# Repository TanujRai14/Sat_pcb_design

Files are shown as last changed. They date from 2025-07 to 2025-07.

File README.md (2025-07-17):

# Can Satellite PCB Design

This repository contains the PCB design files and documentation for a Can Satellite, featuring multiple environmental and orientation sensors, power management, and wireless communication capabilities. The board is designed for compactness and reliability, suitable for satellite and high-altitude balloon missions.

---

## Sensors Integrated

- **BMP280**: Pressure and temperature sensor  
- **MPU6050**: Accelerometer and gyroscope  
- **LM35**: Analog temperature sensor  
- **MQ135**: Air quality/gas sensor  
- **DHT11**: Temperature and humidity sensor  

## Key Components

- **ESP32**  
  - Handles main processing  
  - Supports I2C and SPI communication for peripherals  
- **TP4056 Charging Module**  
  - Li-ion battery charging management  
- **AMS1117**  
  - 3.3V voltage regulator  
- **LoRa SX1278**  
  - Long-range wireless communication module  

---

## PCB Design Details

- **Track Widths**  
  - **5V Supply:** 0.5 mm  
  - **3.3V Supply:** 0.3 mm  
  - **Signal Traces:** 0.2 mm  

- **Layer Stackup**
  - **Top Layer:** Signals and GND  
  - **First Inner Layer:** GND plane  
  - **Second Inner Layer:** Power plane  
  - **Bottom Layer:** Signals and 5V pad  

---

## Power Management

- **Input:** Li-ion battery (managed by TP4056)
- **Regulation:** AMS1117 provides 3.3V for logic and sensors
- **Separate power and ground planes** for noise reduction and stable operation

---

## Communication

- **LoRa SX1278** for long-range, low-power wireless data transmission
- **ESP32** serves as the central controller, interfacing with sensors and modules via I2C/SPI

---

## Notes

- Carefully matched track widths for power and signal integrity
- Dedicated inner layers for ground and power to minimize noise
- Suitable for CubeSat, CanSat, and other small satellite or experimental payloads

## Photos






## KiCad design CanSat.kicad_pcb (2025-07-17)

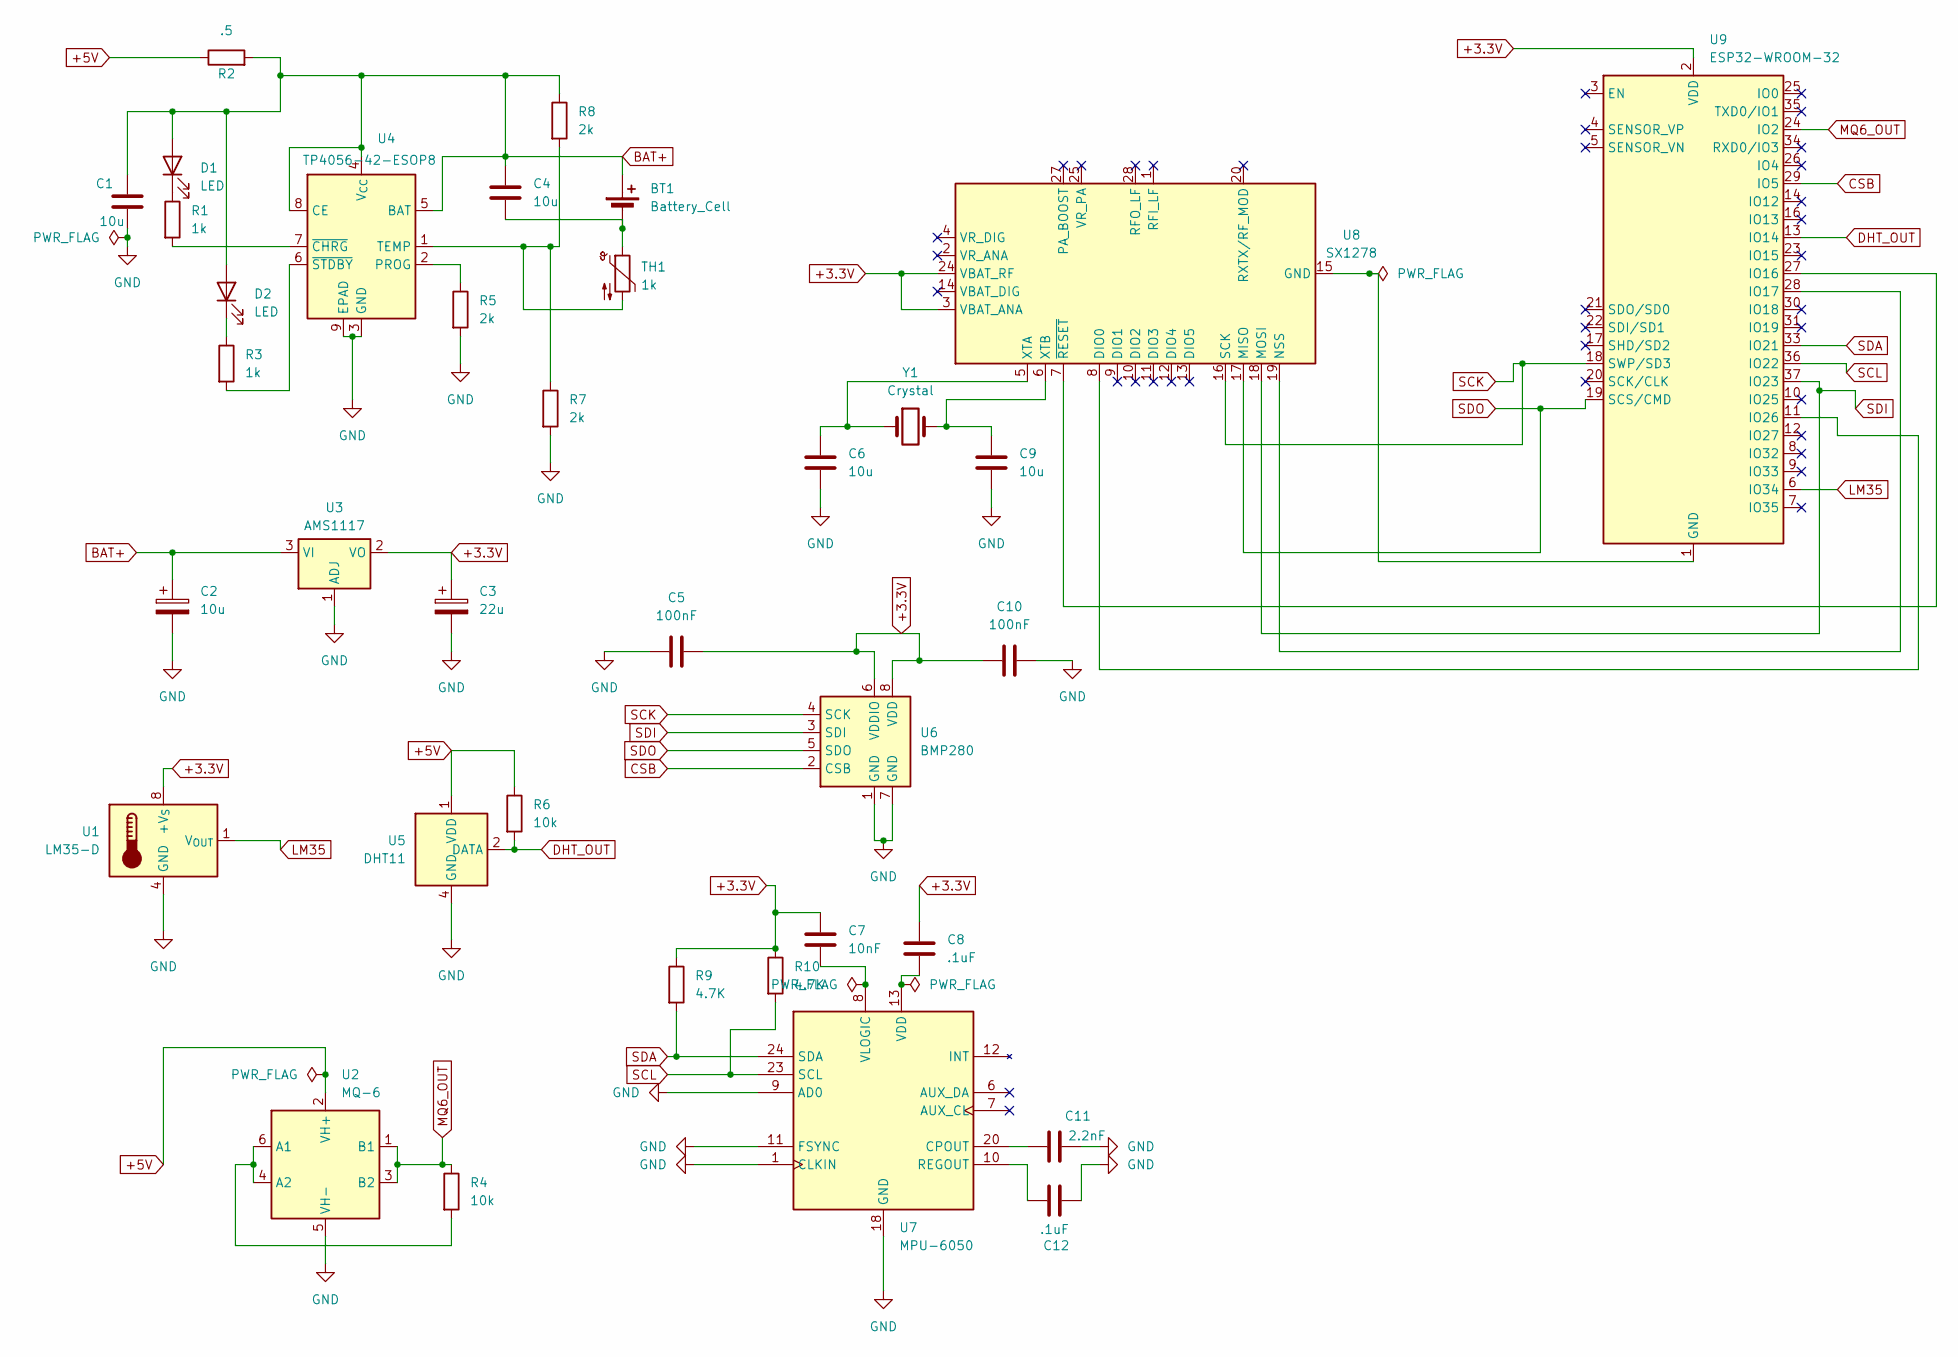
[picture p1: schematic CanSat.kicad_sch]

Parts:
BT1: Battery_Cell
C1, C4, C6, C9: 10u; C_0805_2012Metric
C2: 10u; CP_Radial_D10.0mm_P5.00mm
C3: 22u; CP_Radial_D10.0mm_P5.00mm
C5, C10: 100nF; C_0805_2012Metric
C7: 10nF; C_0805_2012Metric
C8, C12: .1uF; C_0805_2012Metric
C11: 2.2nF; C_0805_2012Metric
D1, D2: LED; LED_0805_2012Metric
R1, R3: 1k; R_0805_2012Metric
R2: .5; R_0805_2012Metric
R4, R6: 10k; R_0805_2012Metric
R5, R7, R8: 2k; R_0805_2012Metric
R9, R10: 4.7K; R_0805_2012Metric
TH1: 1k; R_0805_2012Metric
U1: LM35-D; SOIC-8_3.9x4.9mm_P1.27mm
U2: MQ-6
U3: AMS1117; SOT-223-3_TabPin2
U4: TP4056-42-ESOP8; SOIC-8-1EP_3.9x4.9mm_P1.27mm_EP2.41x3.3mm_ThermalVias
U5: DHT11; Aosong_DHT11_5.5x12.0_P2.54mm
U6: BMP280; Bosch_LGA-8_2x2.5mm_P0.65mm_ClockwisePinNumbering
U7: MPU-6050; InvenSense_QFN-24_4x4mm_P0.5mm
U8: SX1278; QFN-28-1EP_6x6mm_P0.65mm_EP4.8x4.8mm
U9: ESP32-WROOM-32
Y1: Crystal; Crystal_SMD_Abracon_ABM7-2Pin_6.0x3.5mm

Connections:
+3.3V: C3.1, C5.2, C7.2, C8.1, C10.1, R9.1, R10.1, U1.8 (+V_{S}), U3.2 (VO), U6.6 (VDDIO), U6.8 (VDD), U8.3 (VBAT_ANA), U8.24 (VBAT_RF), U9.2 (VDD)
+5V: R2.1, R6.1, U2.2 (VH+), U5.1 (VDD)
BAT+: BT1.1 (+), C1.1, C2.1, C4.1, D1.2 (A), D2.2 (A), R2.2, R8.1, U3.3 (VI), U4.4 (V_{CC}), U4.5 (BAT), U4.8 (CE)
CSB: U6.2 (CSB), U9.29 (IO5)
DHT_OUT: R6.2, U5.2 (DATA), U9.13 (IO14)
GND: C1.2, C2.2, C3.2, C5.1, C6.2, C9.2, C10.2, C11.2, C12.2, R5.2, R7.2, U1.4 (GND), U2.5 (VH-), U3.1 (ADJ), U4.3 (GND), U4.9 (EPAD), U5.4 (GND), U6.1 (GND), U6.7 (GND), U7.1 (CLKIN), U7.9 (AD0), U7.11 (FSYNC), U7.18 (GND)
LM35: U1.1 (V_{OUT}), U9.6 (IO34)
MQ6_OUT: R4.1, U2.1 (B1), U2.3 (B2), U9.24 (IO2)
unnamed: BT1.2 (-), C4.2, TH1.1
unnamed: D1.1 (K), R1.1
unnamed: D2.1 (K), R3.1
unnamed: R4.2, U2.4 (A2), U2.6 (A1)
unnamed: R5.1, U4.2 (PROG)
unnamed: R7.1, R8.2, TH1.2, U4.1 (TEMP)
unnamed: R1.2, U4.7 (~CHRG)
unnamed: R3.2, U4.6 (~STDBY)
unnamed: C11.1, U7.20 (CPOUT)
unnamed: C12.1, U7.10 (REGOUT)
unnamed: C8.2, U7.13 (VDD)
unnamed: C7.1, U7.8 (VLOGIC)
unnamed: U8.8 (DIO0), U9.11 (IO26)
unnamed: U8.15 (GND), U8.21 (GND), U8.22 (GND), U8.23 (GND), U8.26 (GND), U8.29 (GND), U9.1 (GND), U9.15 (GND), U9.38 (GND), U9.39 (GND)
unnamed: U8.19 (NSS), U9.28 (IO17)
unnamed: C6.1, U8.5 (XTA), Y1.1
unnamed: C9.1, U8.6 (XTB), Y1.2
unnamed: U8.7 (~RESET), U9.27 (IO16)
SCK: U6.4 (SCK), U8.16 (SCK), U9.18 (SWP/SD3)
SCL: R10.2, U7.23 (SCL), U9.36 (IO22)
SDA: R9.2, U7.24 (SDA), U9.33 (IO21)
SDI: U6.3 (SDI), U8.18 (MOSI), U9.37 (IO23)
SDO: U6.5 (SDO), U8.17 (MISO), U9.19 (SCS/CMD)

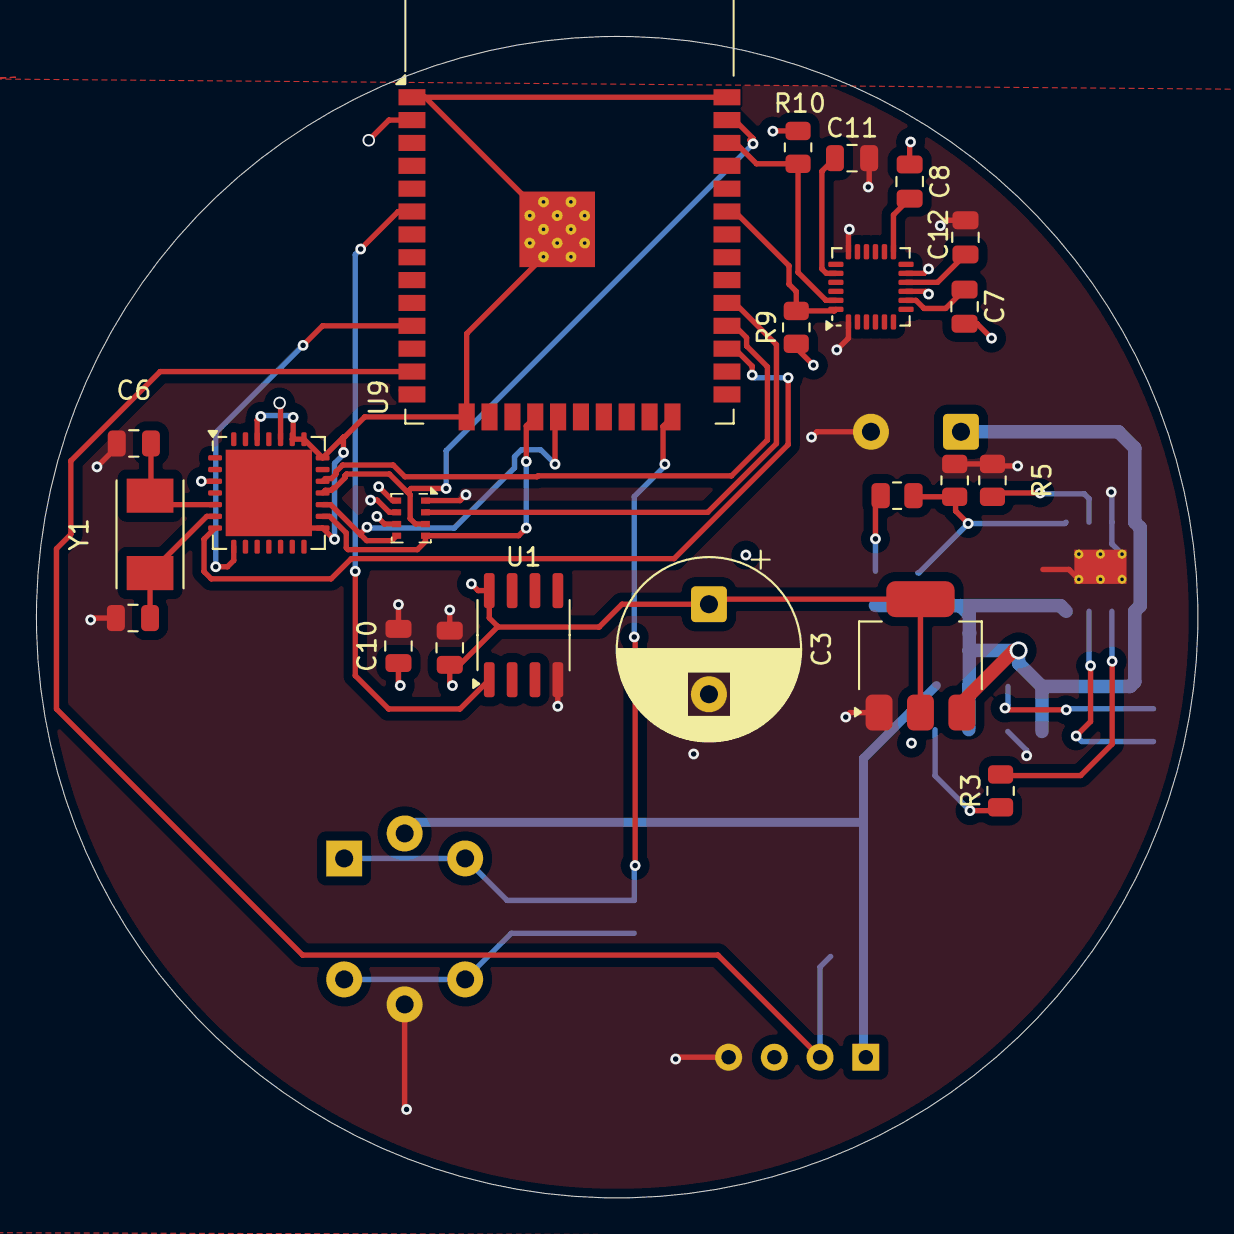
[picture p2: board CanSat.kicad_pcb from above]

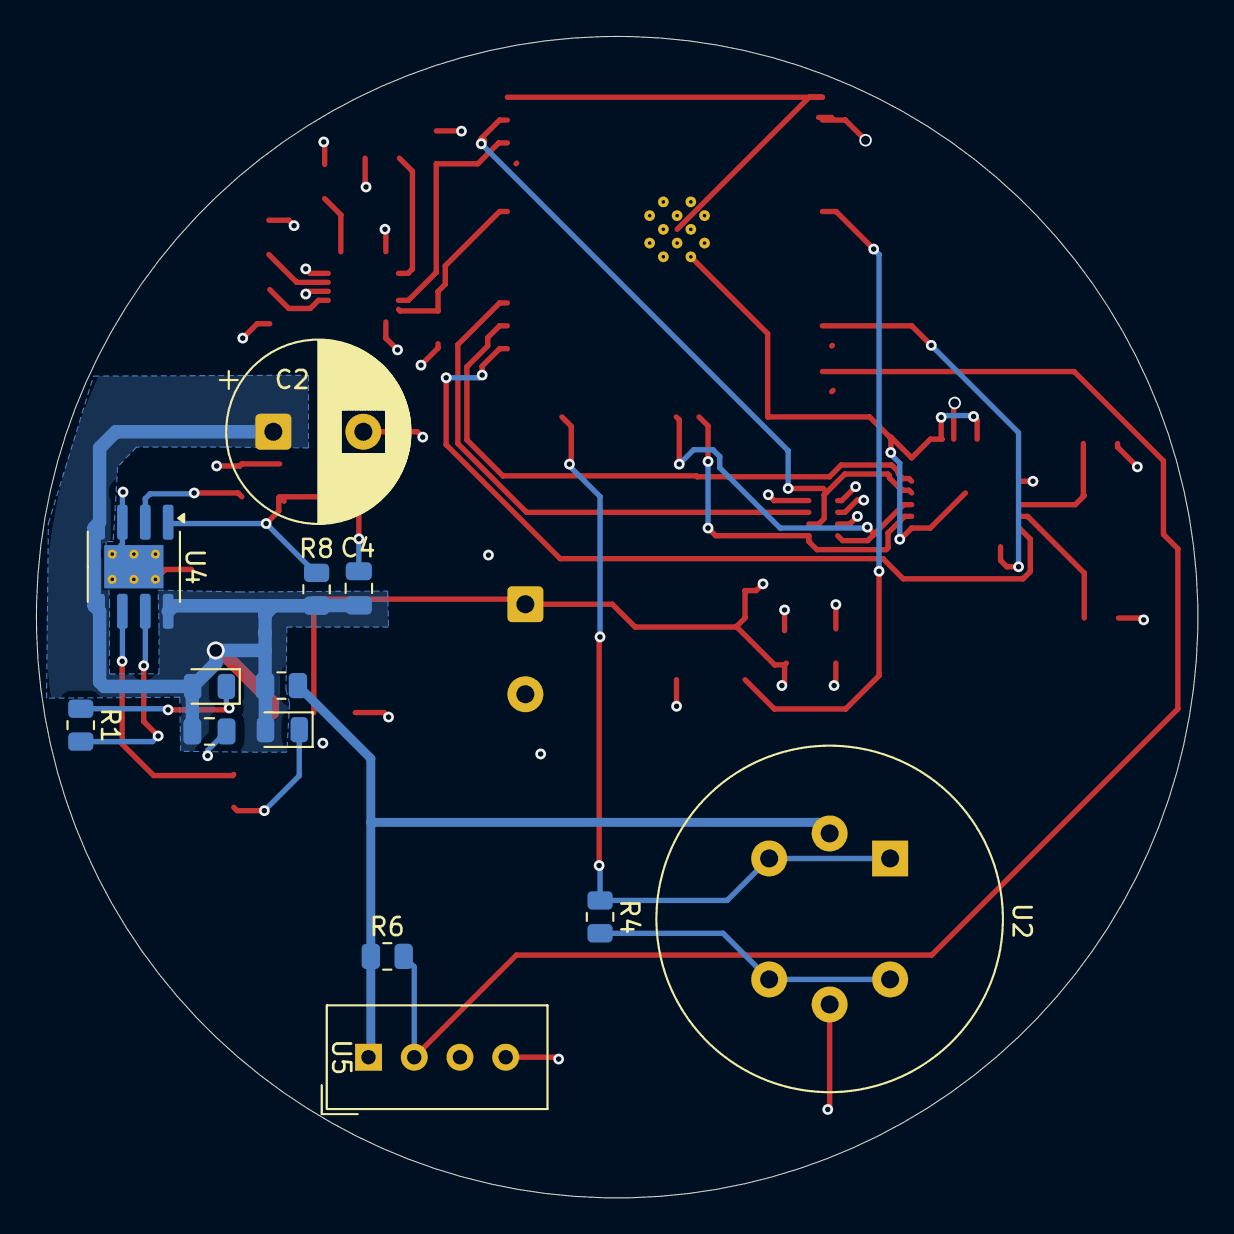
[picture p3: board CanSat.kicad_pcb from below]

Board: 4 copper layers, 64.5 x 64.5 mm, 35 parts (13 on the bottom side), 31 nets.

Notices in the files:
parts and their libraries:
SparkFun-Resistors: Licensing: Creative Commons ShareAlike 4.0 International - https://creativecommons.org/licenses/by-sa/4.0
